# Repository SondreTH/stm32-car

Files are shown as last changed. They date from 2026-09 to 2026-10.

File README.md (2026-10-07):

# Team 7 Autonomous Car (MR2006B)

This is the code for our autonomous car in the MR2006B Industrial Automation course at
Tecnológico de Monterrey. The car has to drive a circuit of about 150 m by itself, stop
for 10 seconds at three waypoints, avoid obstacles and end where it started. Everything
is controlled by an STM32 Nucleo F446RE board.

## How it works

- **Position:** An encoder on the rear motor measures how far the car has driven, and an
  MPU6050 gyro measures which direction it is pointing. From this the car calculates its
  x and y position 100 times per second.
- **Recording and replaying the route:** First we drive the course manually over Bluetooth
  while the car saves its own path and the waypoints. In automatic mode the car follows
  the saved path using pure pursuit, and slows down to stop on each waypoint.
- **Speed control:** A PI controller uses the encoder to keep the car at the speed we ask for.
- **Obstacles:** An HC SR04 ultrasonic sensor makes the car stop if something is in front of it.
  If the obstacle does not move, the car backs up and drives around it.
- **Communication:** Commands and telemetry (CSV) over Bluetooth and over USB.

## Hardware

| Part | Model |
|---|---|
| Microcontroller | STM32 Nucleo F446RE |
| Drive motor | 25GA370 12 V DC motor with gearbox and encoder |
| Motor driver | L298N |
| Steering | MG996R servo |
| Gyro | MPU6050 |
| Distance sensor | HC SR04 |
| Bluetooth | BT04A (ZS040) |
| Power | 3S LiPo battery, XL4015 buck converter for the servo |

## Folders

| Folder | What is inside |
|---|---|
| `cubeide/` | STM32CubeIDE project (`Team7_Car.ioc` and the C code) |
| `tools/` | Python programs for logging, plotting runs and making paths, plus a simulator |
| `cad/` | 3D printed parts (top plate and sensor holder) |
| `wiring/` | Wiring guide for the circuit board |

How to set up the CubeIDE project is explained in `cubeide/README_CubeIDE.md`.

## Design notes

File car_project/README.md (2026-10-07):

# MR2006B car – complete software v1.3

```
car_project/
  cubeide/          STM32CubeIDE project (Team7_Car.ioc + C code), see cubeide/README_CubeIDE.md
    Team7_Car/Core/Src/car_config.c   every tunable number            <- you edit this
    Team7_Car/Core/Inc/path_data.h    the route the car drives in AUTO <- replaced by DUMP
  tools/            laptop tools (Python 3: pip install pyserial matplotlib)
    car_console.py  terminal + automatic telemetry log + path saving
    plot_run.py     plot a run (where the car went vs. the path)
    path_builder.py make a path from measured legs (alternative to TEACH)
    sim.cpp         PC simulation of the autopilot (optional)
  cad/              3D-printable deck plate + HC-SR04 bracket (.scad + .stl)
  wiring/           team7_wiring.html - perfboard wiring guide (open in a browser)
```

The firmware is the CubeIDE project. It matches the soldered perfboard (servo on PB10 / CN10-25).
(An older Arduino IDE version lived in `car_firmware/`; it was removed but is still in the git history.)

**How the car works**
- **Distance** comes from the encoder. **Heading** comes from the MPU-6050 gyro. Together they give the car's **x/y position**.
- In **TEACH** mode you drive the course once over Bluetooth. The car records its own x/y track, and you mark the 3 waypoints and the finish.
- In **AUTO** the car replays that track by steering toward a point 0.6 m ahead on the path (pure pursuit).
  - It slows down and stops exactly at each waypoint, waits 10 s, and ends at the start.
- **Obstacles:**
  - If something is closer than 40 cm, the car stops and waits.
  - If it's still there after 4 s, the car backs up and drives around it (worth 2 points).
- **Why teach-and-repeat:** errors like a slightly wrong gyro scale are the same during teaching and replay, so they cancel out.
  - In the simulation, a 3 % gyro error gave 1–2 cm waypoint error with a taught path.
  - The same error gave 50–220 cm with a path measured from the map.
  - Real runs will be worse than 1–2 cm, because wheel slip and random drift don't cancel.

---

## 1. Build and flash (STM32CubeIDE)

1. Follow `cubeide/README_CubeIDE.md` section 1 to create the project from `Team7_Car.ioc`, then build and **Run** to flash.
2. Talk to the car with any serial terminal on the ST-LINK COM port at **115200** baud, line ending **Newline**, or with `tools/car_console.py` (better: it logs).

## 2. Wiring

| Part | Part pin | Nucleo pin | Header |
|---|---|---|---|
| Encoder | A / B | PA0 / PA1 | A0 / A1 |
| Encoder | VCC / GND | 3V3 / GND | |
| L298N | ENA (remove jumper) / IN1 / IN2 | PA8 / PB4 / PB5 | D7 / D5 / D4 |
| Servo | signal | PB10 | D6 |
| HC-SR04 | TRIG / ECHO (ECHO via 1k–2k divider) | PB6 / PA7 | D10 / D11 |
| Bluetooth | TXD / RXD | PA10 / PA9 | D2 / D8 |
| MPU-6050 | SDA / SCL | PB9 / PB8 | D14 / D15 |
| Battery monitor | battery+ → 10k → pin → 3.3k → GND | PA4 | A2 |

**Power:**
- Battery → switch → fuse feeds three things:
  - the L298N (motor)
  - a 6 V buck converter (servo only)
  - the 5 V module (Nucleo E5V + sensors)
- All grounds are common.
- Keep the car still for 2 s after power-on while the gyro calibrates.

## 3. This week: sensor bring-up (encoder, gyro, distance sensor)

Send `T 10` to get telemetry. With `car_console.py` it's saved to `tools/logs/` automatically. Record the results in the table in section 9.

**Encoder**
1. **Direction.** Lift the rear wheels and turn one forward by hand: `counts` must go up. If not, set `ENCODER_INVERT` in `car_config.h`.
2. **Motor direction.** Send `P 30`: the wheels must turn forward. If not, set `MOTOR_INVERT` in `car_config.h`. `X` stops.
3. **Deadband.** Send `P 5`, `P 10`, `P 15`, … The lowest value that reliably moves the car is the deadband. Set it with `B`.
4. **Counts per metre (most important).**
   - Send `Z`, then `P 40` along a tape. Send `X` after about 5 m.
   - Counts per metre = counts ÷ metres. Do it 3 times and average. Set it with `C` and in `car_config.c`.
5. **Top speed.** Send `P 100` and read `v_mps`. Set `SPEED_FF ≈ (100 − deadband) / top_speed`.
6. **Speed loop.** Send `V 0.3`: `v_mps` should follow `set_mps` without oscillating. If it oscillates, lower KP. If it's slow to reach the setpoint, raise KI.
7. **Distance.** Send `Z` then `D 5`, 5 times. Stops within a few cm of each other means the encoder is good.

**Steering**

8. **Limits.** Step `U 1500` by 25 µs (`U 1525`, `U 1550`, …) to each end stop. Back off 25 µs if the servo strains. Set `SL`, `SR`, `SC`.
9. **Angle scale.** Send `S 20` and measure the front-wheel angle (a phone protractor app works).
   - Set `SERVO_US_PER_DEG` so that `S 20` really gives 20°.
   - The autopilot depends on this.
10. **Wheelbase and sonar position.**
    - Measure from the front axle to the rear axle and put it in `WHEELBASE_M`.
    - Measure from the rear axle to the sonar face and put it in `SONAR_X_M`.

**Gyro**

11. **Found.** `G` must show `IMU OK`.
12. **Direction.** Send `Z` and rotate the car left by hand: `heading_deg` must go up. If not, set `GYRO_INVERT` in `car_config.h`.
13. **Scale (don't skip).**
    - Put the car against a wall edge, send `Z`, and turn it 5 full turns left. Put it back against the edge.
    - Set `GYRO_SCALE = 1800 / heading shown`.
    - Check it with 5 turns right.
14. **Drift.**
    - Wheels lifted: send `Z`, then `P 30`. After 3 minutes, `heading_deg` should be within about 2°.
    - Standing still, the car corrects its own drift, so test with the motor running.

**Distance sensor**

15. Check `sonar_cm` against a tape at 20, 50 and 100 cm. 400 means nothing is seen.
16. Walk around the car outdoors. It must NOT see the ground, a curb or the step. If it does, mount it higher or tilt it up (the printed bracket has a 3° tilt).

**Put it together**

17. **Odometry.** Send `Z`, drive an L-shape with `V`/`S`, stop, and compare `x_m`, `y_m` with a tape.
18. **Indoor autopilot test.** The built-in demo path is 2 m straight → stop → 90° left turn → 1 m → finish. It needs about 2 × 3 m of floor.
    - Put the car down and press the blue button (or send `GO`).
    - It stops after 2 m for 10 s, then turns and finishes.
19. **Obstacle test.** Run the demo again and step in front of the car.
    - It should stop, then continue when you step away.
    - Put a box in front instead: after 4 s it should back up and drive around the box.

## 4. Commands

| Command | Does |
|---|---|
| `X` | Stop. Also aborts AUTO |
| `V 0.3` / `S 15` | Speed (m/s) / steering (° , + = left) |
| `P 40` / `D 5` | Open-loop motor % / drive 5 m and stop |
| `REC` | Start recording a path. The car's position now = START |
| `WP` | Record a waypoint here (car stopped exactly on it) |
| `NOOBS` | Toggle an obstacle-free zone (e.g. passing close to a wall) |
| `END` | Record the finish here and stop recording |
| `GO` | AUTO: 3 s countdown, gyro calibration, then drive the path |
| `PATH` / `DUMP` / `LOAD` | Show path / print it as `path_data.h` / reload the built-in one |
| `AS 0.3` `LA 0.6` `OB 40` `RR 1` `DO 0.6` | Cruise speed, look-ahead, obstacle stop distance, reroute on/off, detour size (+ = pass on the left) |
| `Z` `GC` `GS` `C` `K` `B` `U` `SC/SL/SR` `WB` | Calibration (see section 3) |
| `T 10` `G` `W 1000` `?` | Telemetry rate, settings, watchdog, help |

**Blue button:**
- In AUTO: abort.
- While moving: stop.
- In TEACH, standing still: record a waypoint.
- Otherwise: start AUTO.

## 5. Teaching the course (the "training drive")

1. **Make a start jig.** Mark the START on the ground at the bell: tape where the two rear wheels go, plus a line for the heading.
   The start heading must be identical every time. It's the biggest single error source.
2. **Set up the phone.** In Serial Bluetooth Terminal, create macro buttons:
   `V 0.2`, `X`, `S 25`, `S 12`, `S 0`, `S -12`, `S -25`, `WP`, `END`.
3. **Start recording.** Put the car in the jig and send `REC`. It calibrates the gyro for 1 s: don't touch it.
4. **Drive the course slowly** (`V 0.2`), in the middle of the sidewalk.
   - Stay away from edges: the detour needs about 0.6 m of room on one side.
   - Smooth driving gives a smooth path.
5. **At each waypoint:** stop so the car is exactly on the marker, then send `WP` (or press the blue button).
   - Use the same point of the car every time (e.g. the rear axle over the mark), because that's the point AUTO will stop on.
6. **At the finish** (back at the bell): stop exactly in the start position and send `END`.
   - It prints the **loop closure**: how far the odometry thinks the finish is from the start. This is your drift over one lap.
7. **Save it.** Send `DUMP`. `car_console.py` saves it to `tools/saved_paths/`.
   - Copy that file over `cubeide/Team7_Car/Core/Inc/path_data.h`, then build and flash. The path is now permanent.
   - To test without re-uploading, `!upload <file>` in the console sends a path into the car's RAM.
8. **Replay.** Put the car in the jig and press the button. Check the waypoint errors and plot the run: `python plot_run.py logs/run_….csv --path ../cubeide/Team7_Car/Core/Inc/path_data.h`.

**Improving accuracy:**
- Run 3 times and measure where the car stops at each waypoint.
- If an error is the same every run, it can be corrected. Nudge that waypoint's x/y in `path_data.h`, or re-teach.
- If the car cuts corners, lower `LA` (look-ahead). If it wobbles on straights, raise it.
- **Time check:** 150 m at 0.3 m/s plus 3 × 10.5 s ≈ 9 min, inside the 15 min limit.
  - Don't go below about 0.2 m/s average.
  - `AS` sets the cruise speed.

## 6. Laptop tools

```
pip install pyserial matplotlib
python tools/car_console.py                 # lists ports
python tools/car_console.py COM5            # USB (115200)
python tools/car_console.py COM7 9600       # Bluetooth COM port
python tools/plot_run.py tools/logs/run_XXXX.csv --path cubeide/Team7_Car/Core/Inc/path_data.h
python tools/path_builder.py tools/course_example.txt -o cubeide/Team7_Car/Core/Inc/path_data.h
```

- **Over Bluetooth:** use `T 5` rather than `T 10`, because 9600 baud is slow.
- **The simulator (optional):** runs the real autopilot code (`cubeide/.../path.c`, `autopilot.c`) on a simulated course.
  Build instructions are at the top of `tools/sim.cpp`, then `./sim 0.01 t`.

## 7. 3D-printed parts (`cad/`)

- **`deck_plate`** – an extra top layer, 180 × 110 × 3 mm.
  - It has a 10 mm grid of M3 holes (screws or zip ties anywhere) and two cable slots.
  - It mounts on four M3 brass standoffs.
  - **Before printing:** measure the spacing of the 4 holes you'll use in the existing upper plate. Set `mount_x` / `mount_y` in the `.scad` file and export a new STL in OpenSCAD (free).
- **`sonar_bracket`** – holds the HC-SR04 at 45 mm height, tilted 3° up. Two slots screw it to the front plate.
  - Check the eye spacing (26 mm) with calipers first.
- **Print:** PLA or PETG, 0.2 mm layers, 20 % infill, no supports.

## 8. Race-day checklist

- [ ] Battery charged, and the voltage shows in `G`
- [ ] The correct `path_data.h` flashed (`PATH` shows 3 STOPs + FINISH)
- [ ] Car in the start jig, heading exact
- [ ] Hands off during the 3 s countdown (gyro calibration)
- [ ] Laptop or phone connected, `T 5` running, to show the telemetry to the professor

## 9. Results table

| Value | Measured |
|---|---|
| ENCODER / MOTOR / GYRO invert | |
| Deadband % | |
| Counts per metre (3 runs) | |
| Top speed at P 100 (m/s) | |
| Servo min / centre / max (µs), µs per degree | |
| Wheelbase, sonar offset (m) | |
| GYRO_SCALE | |
| D 5 result (5 runs) | |
| Loop closure after TEACH (cm) | |
| Waypoint errors, AUTO run 1 / 2 / 3 (cm) | |

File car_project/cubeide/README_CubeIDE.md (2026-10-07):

# Team 7 car – STM32CubeIDE version (v1.3)

The car firmware, written in C with ST's HAL. All pins are set
in **`Team7_Car.ioc`**, so CubeIDE shows them in the Pinout view (the screenshots for the professor).

```
Team7_Car/
  Team7_Car.ioc            CubeMX configuration: pins, clocks, timers, UARTs, I2C, ADC
  Core/Src/main.c          generated by CubeMX + 2 lines of ours (App_Init, App_Loop)
  Core/Src/car_app.c       modes (manual / teach / auto), commands, telemetry
  Core/Src/car_hw.c        encoder, motor, servo, HC-SR04, MPU-6050, battery, buttons
  Core/Src/car_comms.c     USB + Bluetooth text I/O (interrupt driven)
  Core/Src/car_drive.c     odometry and PI speed control loop
  Core/Src/path.c          route + pure-pursuit path following
  Core/Src/autopilot.c     automatic mode state machine (waypoints, obstacles)
  Core/Src/car_config.c    every tunable number      <- edit this one
  Core/Inc/path_data.h     the route for AUTO        <- replaced by DUMP
  (stm32f4xx_hal_msp.c, stm32f4xx_it.c, stm32f4xx_hal_conf.h, main.h: generated, CubeMX rewrites them)
```

## 1. Open it in STM32CubeIDE

1. **File → New → STM32 Project from an Existing STM32CubeMX Configuration File (.ioc)**.
2. Select `Team7_Car/Team7_Car.ioc`. Keep the language **C**, then press **Finish**.
   - CubeIDE creates the project and generates `Drivers/`, the startup file and the linker script.
3. Copy our **`Core/Inc`** and **`Core/Src`** files into the new project's `Core/Inc` and `Core/Src`, replacing the files there.
4. Double-click `Team7_Car.ioc` and press **Project → Generate Code** (Alt+K).
   - CubeMX rewrites its own parts and keeps everything between `USER CODE BEGIN`/`END`.
5. Build with the hammer icon (Ctrl+B), then **Run** to flash the board.

**If the `.ioc` won't open or CubeMX reports errors,** make it yourself in about 10 minutes with the table in section 3.
Then do step 3 and 4 the same way. The code only depends on the pin **labels** and handle names.

**Check after generating:** `main.c` must still contain `#include "car_app.h"`, `App_Init();` and `App_Loop();`.
If they're gone, add them back inside these sections:
- `/* USER CODE BEGIN Includes */` → `#include "car_app.h"`
- `/* USER CODE BEGIN 2 */` → `App_Init();`
- `/* USER CODE BEGIN 3 */` → `App_Loop();`

## 2. Talk to the car

- **USB:** any serial terminal on the ST-LINK COM port at **115200**, line ending **LF/Newline**.
- **Bluetooth:** the BT module's COM port at **9600**. `tools/car_console.py` works with both.
- The commands, telemetry columns, TEACH/AUTO workflow and bring-up tests are in the main `README.md`, sections 3–5.

## 3. Configuration (for the report, and to rebuild the .ioc by hand)

**Board:** NUCLEO-F446RE.
**Clock:** HSI 16 MHz → PLL (M 16, N 336, P 4) → **84 MHz** SYSCLK. APB1 42 MHz, APB2 84 MHz. All timer clocks 84 MHz.
**SYS:** Debug = Serial Wire, Timebase = SysTick.

| Pin | Mode in CubeMX | User label | Connected to | Perfboard |
|---|---|---|---|---|
| PA0 | TIM5_CH1 (Encoder Mode) | ENC_A | Encoder A | CN7-28 |
| PA1 | TIM5_CH2 (Encoder Mode) | ENC_B | Encoder B | CN7-30 |
| PA2 / PA3 | USART2 TX / RX | USART_TX / USART_RX | ST-LINK virtual COM | – |
| PA4 | ADC1_IN4 | BATT_SENSE | Battery divider 10k / 3.3k | CN7-32 |
| PA5 | GPIO_Output | LD2 | Green LED | – |
| PA7 | GPIO_EXTI7 | SONAR_ECHO | HC-SR04 ECHO (via divider) | CN10-15 |
| PA8 | TIM1_CH1 (PWM Generation CH1) | MOTOR_ENA | L298N ENA | CN10-23 |
| PA9 / PA10 | USART1 TX / RX | BT_TX / BT_RX | Bluetooth RXD / TXD | CN10-21 / CN10-33 |
| PB0 | GPIO_Input, pull-up | START_BTN | Start button to GND | CN7-34 |
| PB10 | TIM2_CH3 (PWM Generation CH3) | SERVO_PWM | Servo signal | CN10-25 |
| PB4 | GPIO_Output | MOTOR_IN1 | L298N IN1 | CN10-27 |
| PB5 | GPIO_Output | MOTOR_IN2 | L298N IN2 | CN10-29 |
| PB6 | GPIO_Output | SONAR_TRIG | HC-SR04 TRIG | CN10-17 |
| PB8 / PB9 | I2C1 SCL / SDA | IMU_SCL / IMU_SDA | MPU-6050 | CN10-3 / CN10-5 |
| PC13 | GPIO_Input | B1 | Blue user button | – |

**Peripheral settings**

| Peripheral | Settings | Why |
|---|---|---|
| TIM1 | Clock internal, CH1 PWM, Prescaler 0, Period 16799 | Motor PWM 84 MHz / 16800 = **5 kHz** |
| TIM2 | Clock internal, CH3 PWM, Prescaler 83, Period 19999, Pulse 1500 | 1 tick = 1 µs, 20 ms period = **50 Hz servo** on PB10 |
| TIM5 | Combined channels: Encoder Mode TI1 and TI2, Period 4294967295, Input filter 6 (both); GPIO pull-up on PA0/PA1 | 32-bit hardware quadrature counting (x4) |
| USART1 | Asynchronous, 9600 baud, global interrupt ON | Bluetooth |
| USART2 | Asynchronous, 115200 baud, global interrupt ON | USB virtual COM |
| I2C1 | Fast Mode 400 kHz, on PB8/PB9 | MPU-6050 |
| ADC1 | IN4, 12-bit, software start, sampling 480 cycles | Battery voltage |
| NVIC | EXTI line[9:5], USART1, USART2 enabled | Sonar echo timing, serial RX/TX |

**Same wiring as the soldered board.**
- The servo stays on **PB10 (CN10-25)** with real hardware PWM from TIM2 channel 3.
- The encoder stays on PA0/PA1 but is counted by **TIM5**, because TIM2 is busy with the servo.
- Microsecond timing (sonar) comes from SysTick, so no extra timer is needed.

## 4. Screenshots for the professor

In CubeIDE with `Team7_Car.ioc` open:

1. **Pinout view:** the whole chip with all labels. Right-click → *Pinout* to zoom in if needed.
2. **System view → TIM5:** encoder mode settings.
3. **TIM1 and TIM2:** PWM parameters (prescaler, period).
4. **USART1, USART2, I2C1, ADC1:** parameter settings.
5. **NVIC:** enabled interrupts.
6. **Clock Configuration tab:** 84 MHz clock tree.

## 5. Debugging with Live Expressions

Run → **Debug**, then add these in the *Live Expressions* view:

- **Encoder and speed:** `drv.distance`, `drv.speed`, `drv.setpoint`, `motorPct`, `TIM5->CNT`
- **Gyro:** `headingDeg`, `gyroRateDps`, `gyroBiasDps`, `imuOk`
- **Position and sensors:** `drv.x`, `drv.y`, `sonarCm`, `steerDeg`, `battV`
- **Autonomous mode:** `carMode`, `ap.state`, `fol.sNow`, `fol.cte`

If a value shows *optimized out*, set the build to **Debug** (`-Og`).

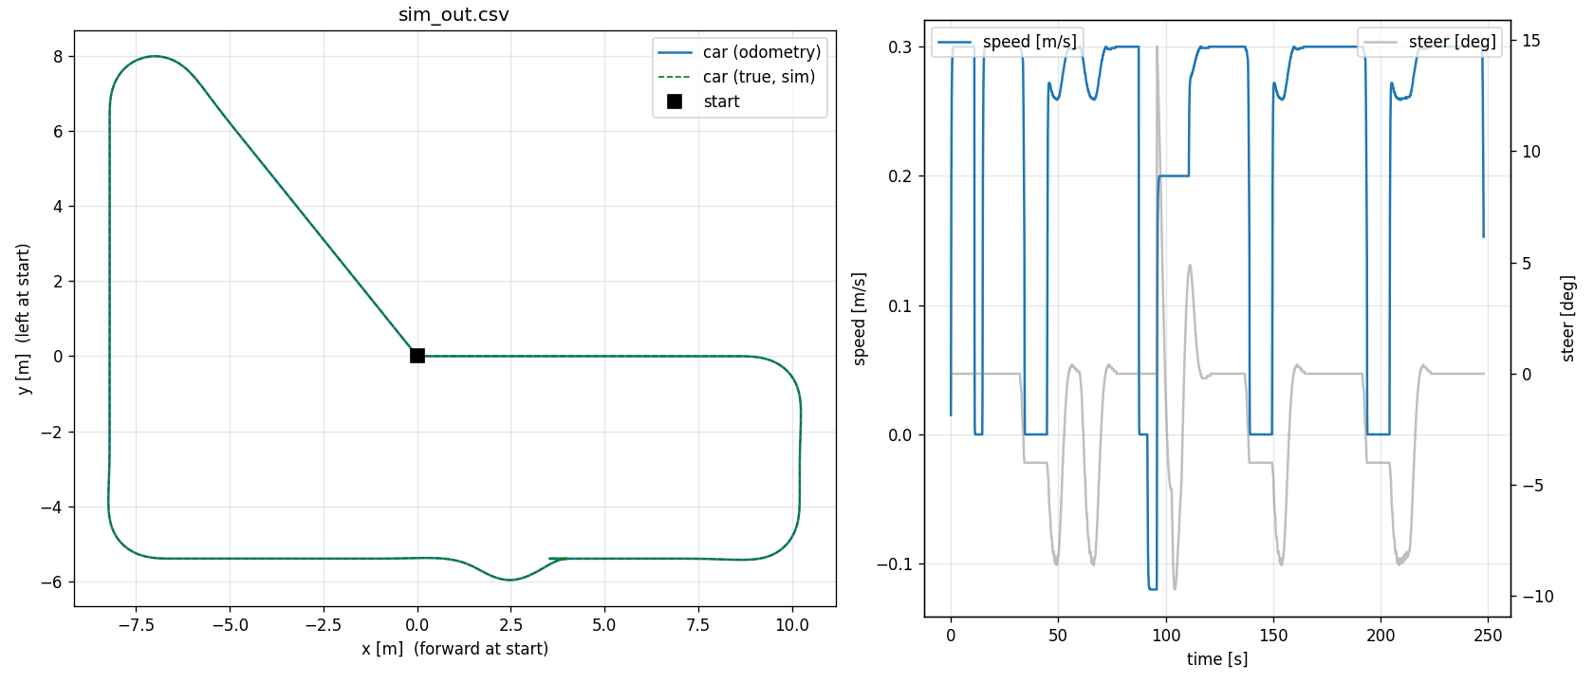
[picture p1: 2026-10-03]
car_project/tools/sim_example.png

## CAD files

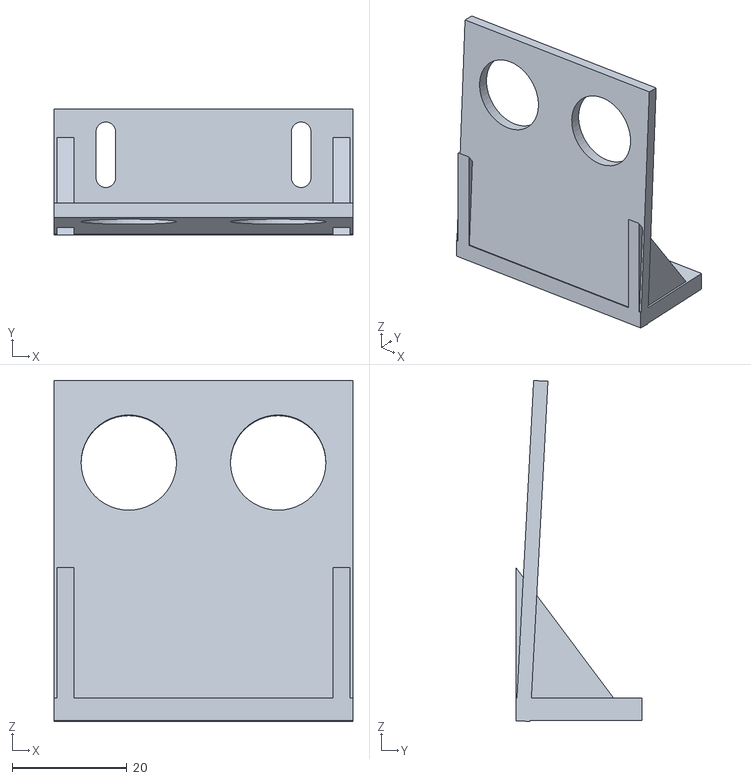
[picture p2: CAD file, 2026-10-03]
car_project/cad/sonar_bracket.stl
52.0 x 22.0 x 59.3

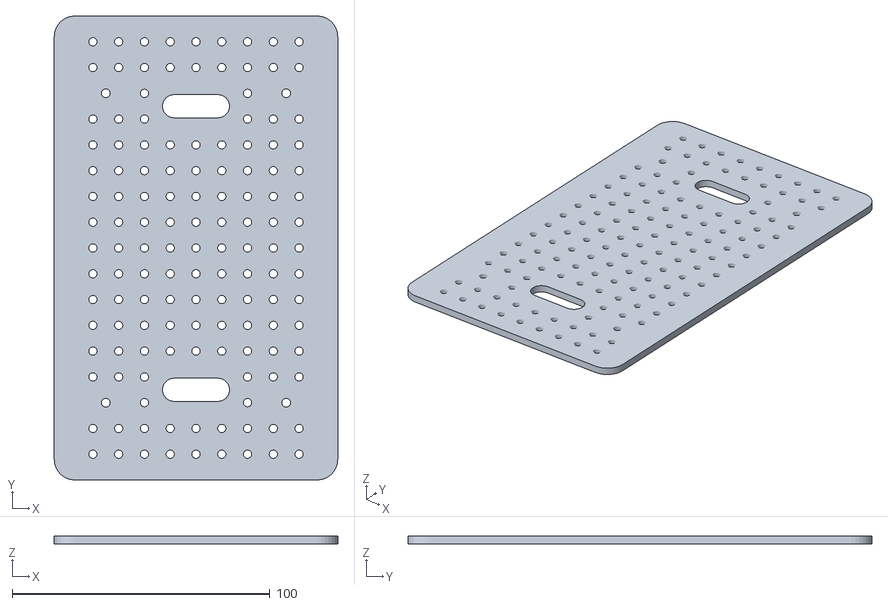
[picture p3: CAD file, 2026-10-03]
car_project/cad/deck_plate.stl
110.0 x 180.0 x 3.00

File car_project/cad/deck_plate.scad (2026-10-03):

// =====================================================================
//  deck_plate.scad  -  extra top deck for the MR2006B car
//
//  A flat plate with a 10 mm grid of M3 holes (screws, standoffs or zip
//  ties anywhere), 4 mounting holes for brass standoffs, and two cable
//  slots. Mount it on M3 brass standoffs screwed into the existing upper
//  plate.
//
//  HOW TO FIT IT TO YOUR CAR (2 minutes with a ruler):
//   1. Pick 4 holes in the existing upper plate for the new standoffs.
//   2. Measure their centre-to-centre spacing across (x) and along (y).
//   3. Put the numbers in mount_x / mount_y below (or edit mount_holes).
//   4. OpenSCAD (free): F6 to render, File > Export > STL. Print flat.
//  Print: PLA/PETG, 0.2 mm layers, 3 walls, 20 % infill, no supports.
// =====================================================================

/* [Plate] */
plate_w      = 110;   // across the car (x), mm
plate_l      = 180;   // along the car (y), mm
thickness    = 3;     // mm (3 is stiff enough; 4 for a heavy battery)
corner_r     = 8;

/* [Mounting to the chassis] */
mount_x      = 70;    // centre-to-centre spacing across, mm   <- MEASURE
mount_y      = 120;   // centre-to-centre spacing along, mm    <- MEASURE
mount_offset_y = 0;   // shift the hole pattern forward (+) / back (-)
mount_d      = 3.4;   // M3 clearance
mount_boss_d = 9;     // solid ring around each mounting hole

/* [Grid] */
grid_pitch   = 10;
grid_d       = 3.2;   // fits M3 screws and 2.5 mm zip ties
edge_margin  = 6;

/* [Cable slots] */
slot_w       = 26;
slot_h       = 9;
slot_y       = [55, -55];   // positions along the car (0 = centre)

$fn = 32;

mount_holes = [for (sx = [-1, 1], sy = [-1, 1]) [sx * mount_x / 2, sy * mount_y / 2 + mount_offset_y]];

module rounded_rect(w, l, r, h) {
  linear_extrude(h)
    offset(r) offset(-r) square([w, l], center = true);
}

function near_mount(p) = min([for (m = mount_holes) norm(p - m)]) < mount_boss_d / 2 + grid_d / 2 + 1;
function in_slot(p) = len([for (sy = slot_y) if (abs(p[0]) < slot_w / 2 + grid_d && abs(p[1] - sy) < slot_h / 2 + grid_d) 1]) > 0;

difference() {
  rounded_rect(plate_w, plate_l, corner_r, thickness);

  // mounting holes
  for (m = mount_holes) translate([m[0], m[1], -1]) cylinder(d = mount_d, h = thickness + 2);

  // grid
  nx = floor((plate_w - 2 * edge_margin) / grid_pitch / 2);
  ny = floor((plate_l - 2 * edge_margin) / grid_pitch / 2);
  for (ix = [-nx : nx], iy = [-ny : ny]) {
    p = [ix * grid_pitch, iy * grid_pitch];
    if (!near_mount(p) && !in_slot(p))
      translate([p[0], p[1], -1]) cylinder(d = grid_d, h = thickness + 2);
  }

  // cable slots
  for (sy = slot_y)
    translate([0, sy, -1]) linear_extrude(thickness + 2)
      offset(slot_h / 2 - 0.01) square([slot_w - slot_h, 0.02], center = true);
}

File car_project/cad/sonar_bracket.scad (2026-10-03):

// =====================================================================
//  sonar_bracket.scad  -  front bracket for the HC-SR04
//
//  The two "eyes" push through the round holes from behind; a drop of
//  hot glue (or two small zip ties) holds the board. The foot has two
//  M3 slots to screw it onto the front bumper plate or the deck.
//
//  Check with calipers before printing: eye diameter (usually 16 mm)
//  and centre-to-centre spacing of the eyes (usually ~26 mm).
//  Print standing on the foot, no supports.
// =====================================================================

eye_d        = 16.6;  // hole for the transducers (16 mm + clearance)
eye_spacing  = 26;    // centre-to-centre                       <- CHECK
face_w       = 52;
face_t       = 2.5;
sensor_h     = 45;    // eye centre height above the foot, mm
                      // (higher = fewer false alarms from the ground)
tilt_up      = 3;     // degrees, aims slightly up to ignore the ground
foot_d       = 22;    // foot depth
foot_t       = 4;
slot_len     = 8;     // M3 slots, lets you adjust the position
slot_spacing = 34;

$fn = 48;
face_h = sensor_h + eye_d / 2 + 6;

difference() {
  union() {
    // foot
    translate([-face_w / 2, 0, 0]) cube([face_w, foot_d, foot_t]);
    // face (tilted back by tilt_up)
    rotate([-tilt_up, 0, 0]) translate([-face_w / 2, 0, 0]) cube([face_w, face_t, face_h]);
    // gussets
    for (sx = [-1, 1])
      translate([sx * (face_w / 2 - 2) - 1.5, 0, 0])
        rotate([90, 0, 90]) linear_extrude(3)
          polygon([[0, 0], [foot_d - 2, 0], [0, face_h * 0.45]]);
  }
  // eyes
  for (sx = [-1, 1])
    rotate([-tilt_up, 0, 0]) translate([sx * eye_spacing / 2, -1, sensor_h])
      rotate([-90, 0, 0]) cylinder(d = eye_d, h = face_t + 2);
  // M3 slots in the foot
  for (sx = [-1, 1])
    translate([sx * slot_spacing / 2, foot_d / 2 + 3, -1]) hull() {
      translate([0, -slot_len / 2, 0]) cylinder(d = 3.4, h = foot_t + 2);
      translate([0,  slot_len / 2, 0]) cylinder(d = 3.4, h = foot_t + 2);
    }
}

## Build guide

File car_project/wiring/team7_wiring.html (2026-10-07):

MR2006B · Team 7 · firmware v1.3

# Team 7 Car Wiring

What to solder where on the perfboard that sits on the NUCLEO-F446RE's inner morpho rows. It matches the pins in Team7_Car.ioc (CubeIDE).

VBAT 11–12.6 V 6 V servo 5 V 3.3 V GND Signal Motor current

## Connector rule

Male pins on the perfboard

Every header J1–J6 on the perfboard is a male pin header. Cables end in female plugs. Your motor/encoder and servo cables already work this way.

Modules: female–female jumpers

The Bluetooth, MPU-6050, HC-SR04 and L298N logic pins are male pins on the module, so connect them with female–female Dupont wires (a 4-wire ribbon keeps them together).

Power: screw terminals

The 5 V and 6 V inputs (J7, J8) and the battery wiring use screw terminals or soldered wire. Dupont plugs can wiggle loose and don't like amps.

Label every plug

J4, J5 and J6 are all 4-pin. Mark each header and its cable with the same colour dot. Swapping them puts 5 V on a signal pin.

## Power

The battery feeds a terminal block (for example WAGO 221). From there each part gets its own supply wire. Only 5 V, 6 V and the battery-sense wire go to the perfboard.

Solder a 1000 µF 16 V capacitor across J2 pins 1–2 (servo), and 100 µF across the 5 V rail. Set both bucks with a multimeter before anything is plugged into them.

## Nucleo pins under the perfboard

Top view, USB end at the top. Your female headers sit on the inner row of each side. Coloured dots are the pins to wire. Row 1 and row 19 are unused, so either end can be cut off.

Leave CN7-18 (+5V) unconnected. With the power jumper on E5V it is the same 5 V anyway, and wiring both invites two supplies fighting when someone moves the jumper.

## Perfboard headers

Pin 1 of each header is listed first. The pin order matches the device or cable, so a straight 4-wire ribbon or the existing plug fits without crossing wires. Check the motor cable colours against your motor's label before soldering J1.

## Before the first power-up

1. Continuity: the GND rail beeps to CN7-20, CN7-22 and CN10-9.
2. No shorts: 5V–GND, 3V3–GND, 6V–GND and VBAT–GND must not beep.
3. Power the bucks with nothing attached. Set 6.0 V (XL4015) and 5.0 V.
4. Power jumper JP5 on E5V. Switch the battery on first, then plug in USB.
5. Measure PA7 (CN10-15) while holding a hand 10 cm in front of the HC-SR04: it must never go above 3.3 V.
6. Only then plug the servo, motor and modules into their headers.

The L298N's 5V screw pin is an output from its own regulator. Connecting it to your 5 V rail makes two supplies fight. Leave it empty.

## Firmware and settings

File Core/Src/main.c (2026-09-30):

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
/* Includes ------------------------------------------------------------------*/
#include "main.h"

/* USER CODE BEGIN PD */
#define IN1_PORT        GPIOA
#define IN1_PIN         GPIO_PIN_8
#define IN2_PORT        GPIOB
#define IN2_PIN         GPIO_PIN_10
/* USER CODE END PD */

TIM_HandleTypeDef htim2;

UART_HandleTypeDef huart1;
UART_HandleTypeDef huart2;

/* USER CODE BEGIN PV */
extern UART_HandleTypeDef huart1;
uint8_t rx_data = 0;
/* USER CODE END PV */

void SystemClock_Config(void);
static void MX_GPIO_Init(void);
static void MX_USART2_UART_Init(void);
static void MX_USART1_UART_Init(void);
static void MX_TIM2_Init(void);
/* USER CODE BEGIN 0 */
volatile int position = 0;
float distance_meters = 0.0;

const float movement = 1.0/1618.0;
/* USER CODE END 0 */

/**
  * @brief  The application entry point.
  * @retval int
  */


int main(void)
{

  /* MCU Configuration--------------------------------------------------------*/

  /* Reset of all peripherals, Initializes the Flash interface and the Systick. */
  HAL_Init();

  /* Configure the system clock */
  SystemClock_Config();

  /* Initialize all configured peripherals */
  MX_GPIO_Init();
  MX_USART2_UART_Init();
  MX_USART1_UART_Init();
  MX_TIM2_Init();
  /* USER CODE BEGIN 2 */
  /* Ensure motors are stopped on startup */
  HAL_GPIO_WritePin(IN1_PORT, IN1_PIN, GPIO_PIN_RESET);
  HAL_GPIO_WritePin(IN2_PORT, IN2_PIN, GPIO_PIN_RESET);

  /* Defining the normal speed which the car drives with*/
  HAL_TIM_PWM_Start(&htim2, TIM_CHANNEL_1);
  __HAL_TIM_SET_COMPARE(&htim2, TIM_CHANNEL_1, 50);
  /* USER CODE END 2 */

  /* Infinite loop */
  /* USER CODE BEGIN WHILE */


  while (1)
  {
	  distance_meters = position*movement;

      /* Bluetooth commands from the phone */
      if (HAL_UART_Receive(&huart1, &rx_data, 1, 10) == HAL_OK)
      {
          switch (rx_data)
          {
              case 'f': /* Drive Forward */
                  HAL_GPIO_WritePin(IN1_PORT, IN1_PIN, GPIO_PIN_SET);
                  HAL_GPIO_WritePin(IN2_PORT, IN2_PIN, GPIO_PIN_RESET);
                  break;

              case 'b': /* Drive Backward */
                  HAL_GPIO_WritePin(IN1_PORT, IN1_PIN, GPIO_PIN_RESET);
                  HAL_GPIO_WritePin(IN2_PORT, IN2_PIN, GPIO_PIN_SET);
                  break;

              case 's': /* Stop */
              default:
                  HAL_GPIO_WritePin(IN1_PORT, IN1_PIN, GPIO_PIN_RESET);
                  HAL_GPIO_WritePin(IN2_PORT, IN2_PIN, GPIO_PIN_RESET);
                  break;

              case '1': /*  (20%) */
                  __HAL_TIM_SET_COMPARE(&htim2, TIM_CHANNEL_1, 20);
                  break;

              case '2': /* (40%) */
                  __HAL_TIM_SET_COMPARE(&htim2, TIM_CHANNEL_1, 40);
                  break;

              case '3': /* (60%) */
                  __HAL_TIM_SET_COMPARE(&htim2, TIM_CHANNEL_1, 60);
                  break;

              case '4': /* (80%) */
                  __HAL_TIM_SET_COMPARE(&htim2, TIM_CHANNEL_1, 80);
                  break;

              case '5': /*  (100%) */
                  __HAL_TIM_SET_COMPARE(&htim2, TIM_CHANNEL_1, 100);
                  break;
          }
      }

      /* Securing the board never freezes */
      __HAL_UART_CLEAR_OREFLAG(&huart1);

    /* USER CODE END WHILE */

    /* USER CODE BEGIN 3 */
  }
  /* USER CODE END 3 */
}

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
/* USER CODE BEGIN 4 */
void HAL_GPIO_EXTI_Callback(uint16_t GPIO_Pin)
{
  /* Checking if ENC_A gave the signal */
  if (GPIO_Pin == ENC_A_Pin)
  {
    /* Checking direction with ENC_B */
    if (HAL_GPIO_ReadPin(ENC_B_GPIO_Port, ENC_B_Pin) == GPIO_PIN_SET)
    {
      position++;
    }
    else
    {
      position--;
    }
  }
}
/* USER CODE END 4 */
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


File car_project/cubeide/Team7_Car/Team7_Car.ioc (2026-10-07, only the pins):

Mcu.UserName=STM32F446RETx
PA0-WKUP.GPIO_Label=ENC_A
PA0-WKUP.Signal=S_TIM5_CH1
PA1.GPIO_Label=ENC_B
PA1.Signal=S_TIM5_CH2
PA10.GPIO_Label=BT_RX
PA10.Signal=USART1_RX
PA13.GPIO_Label=TMS
PA13.Signal=SYS_JTMS-SWDIO
PA14.GPIO_Label=TCK
PA14.Signal=SYS_JTCK-SWCLK
PA2.GPIO_Label=USART_TX
PA2.Signal=USART2_TX
PA3.GPIO_Label=USART_RX
PA3.Signal=USART2_RX
PA4.GPIO_Label=BATT_SENSE
PA4.Signal=ADCx_IN4
PA5.GPIO_Label=LD2 [Green Led]
PA5.Signal=GPIO_Output
PA7.GPIO_Label=SONAR_ECHO
PA7.Signal=GPXTI7
PA8.GPIO_Label=MOTOR_ENA
PA8.Signal=S_TIM1_CH1
PA9.GPIO_Label=BT_TX
PA9.Signal=USART1_TX
PB0.GPIO_Label=START_BTN
PB0.Signal=GPIO_Input
PB10.GPIO_Label=SERVO_PWM
PB10.Signal=S_TIM2_CH3
PB3.GPIO_Label=SWO
PB3.Signal=SYS_JTDO-SWO
PB4.GPIO_Label=MOTOR_IN1
PB4.Signal=GPIO_Output
PB5.GPIO_Label=MOTOR_IN2
PB5.Signal=GPIO_Output
PB6.GPIO_Label=SONAR_TRIG
PB6.Signal=GPIO_Output
PB8.GPIO_Label=IMU_SCL
PB8.Signal=I2C1_SCL
PB9.GPIO_Label=IMU_SDA
PB9.Signal=I2C1_SDA
PC13.GPIO_Label=B1 [Blue PushButton]
PC13.Signal=GPIO_Input
PC14-OSC32_IN.Signal=RCC_OSC32_IN
PC15-OSC32_OUT.Signal=RCC_OSC32_OUT
PH0-OSC_IN.Signal=RCC_OSC_IN
PH1-OSC_OUT.Signal=RCC_OSC_OUT

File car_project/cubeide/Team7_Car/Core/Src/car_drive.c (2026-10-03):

/* car_drive.c - odometry and PI speed control (see car_drive.h) */
#include "car_drive.h"
#include "car_hw.h"
#include "car_config.h"
#include <math.h>

#ifndef M_PI
#define M_PI 3.14159265358979f
#endif

DriveState drv = { DM_STOP, 0, 0, 0, 0, 0, 0, 0, 0, 0, 0, 0, 0, 0.2f, 0, false };

static float clampf_(float v, float lo, float hi) { return v < lo ? lo : (v > hi ? hi : v); }

void drive_stop(void) {
  drv.mode = DM_STOP;
  drv.target = drv.setpoint = 0;
  drv.integ = 0;
  motor_brake();
}
void drive_open(float pct)  { drv.mode = DM_OPEN; drv.openPct = pct; drv.integ = 0; }
void drive_speed(float mps) { drv.mode = DM_SPEED; drv.target = mps; }

void drive_distance(float meters, float cruise) {
  drv.moveStart  = drv.distance;
  drv.moveGoal   = drv.distance + meters;
  drv.moveCruise = fabsf(cruise);
  drv.moveDone   = false;
  drv.mode       = DM_DISTANCE;
}

void drive_zero(void) {
  encoder_zero();
  drv.lastCount = 0;
  drv.distance = 0;
  drv.x = drv.y = 0;
}

/* certainly not moving: braked and no encoder counts for 0.3 s */
bool drive_is_still(void) { return drv.mode == DM_STOP && drv.stillTicks > CONTROL_HZ * 3 / 10; }

/* encoder gives the distance step, gyro the direction (midpoint rule) */
void odometry_update(float headingBeforeDeg, float headingAfterDeg) {
  float ds = drv.lastDelta / COUNTS_PER_METER;
  float th = 0.5f * (headingBeforeDeg + headingAfterDeg) * (float)M_PI / 180.0f;
  drv.x += ds * cosf(th);
  drv.y += ds * sinf(th);
}

/* PI with feed-forward, deadband compensation and anti-windup -> motor % */
static float speed_pi(float sp, float meas, float dt) {
  if (fabsf(sp) < 0.005f) { drv.integ = 0; return 0; }
  float err = sp - meas;
  float u = SPEED_FF * sp + (sp > 0 ? MOTOR_DEADBAND_PCT : -MOTOR_DEADBAND_PCT) + SPEED_KP * err + drv.integ;
  if (fabsf(u) < 100.0f || ((u > 0) != (err > 0))) {
    drv.integ += SPEED_KI * err * dt;
    drv.integ = clampf_(drv.integ, -60.0f, 60.0f);
  }
  return clampf_(u, -100.0f, 100.0f);
}

void drive_update(float dt) {
  /* odometry */
  int32_t c = encoder_count();
  int32_t dc = c - drv.lastCount;
  drv.lastCount = c;
  drv.lastDelta = dc;
  if (dc == 0) { if (drv.stillTicks < 60000) drv.stillTicks++; } else drv.stillTicks = 0;
  float vRaw = (dc / COUNTS_PER_METER) / dt;
  drv.speed += SPEED_LPF * (vRaw - drv.speed);
  drv.distance = c / COUNTS_PER_METER;

  /* distance move: plan the speed from the remaining distance */
  if (drv.mode == DM_DISTANCE) {
    float remaining = drv.moveGoal - drv.distance;
    float dir = (drv.moveGoal >= drv.moveStart) ? 1.0f : -1.0f;
    if (remaining * dir <= MOVE_STOP_TOL) { drive_stop(); drv.moveDone = true; return; }
    float v = sqrtf(2.0f * MOVE_DECEL * fabsf(remaining));
    v = clampf_(v, MOVE_CREEP, drv.moveCruise);
    drv.target = dir * v;
  }

  switch (drv.mode) {
    case DM_STOP: motor_brake(); break;
    case DM_OPEN: motor_set(drv.openPct); break;
    case DM_SPEED:
    case DM_DISTANCE: {
      float step = MAX_ACCEL * dt;
      drv.setpoint += clampf_(drv.target - drv.setpoint, -step, step);
      if (drv.mode == DM_DISTANCE && fabsf(drv.target) < fabsf(drv.setpoint)) drv.setpoint = drv.target;
      if (drv.mode == DM_SPEED && fabsf(drv.target) < 0.005f && fabsf(drv.setpoint) < 0.005f) {
        motor_brake(); drv.integ = 0;
      } else {
        motor_set(speed_pi(drv.setpoint, drv.speed, dt));
      }
      break;
    }
  }
}

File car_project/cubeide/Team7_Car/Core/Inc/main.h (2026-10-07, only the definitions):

#define B1_Pin GPIO_PIN_13
#define B1_GPIO_Port GPIOC
#define ENC_A_Pin GPIO_PIN_0
#define ENC_A_GPIO_Port GPIOA
#define ENC_B_Pin GPIO_PIN_1
#define ENC_B_GPIO_Port GPIOA
#define USART_TX_Pin GPIO_PIN_2
#define USART_TX_GPIO_Port GPIOA
#define USART_RX_Pin GPIO_PIN_3
#define USART_RX_GPIO_Port GPIOA
#define BATT_SENSE_Pin GPIO_PIN_4
#define BATT_SENSE_GPIO_Port GPIOA
#define LD2_Pin GPIO_PIN_5
#define LD2_GPIO_Port GPIOA
#define SONAR_ECHO_Pin GPIO_PIN_7
#define SONAR_ECHO_GPIO_Port GPIOA
#define SONAR_ECHO_EXTI_IRQn EXTI9_5_IRQn
#define START_BTN_Pin GPIO_PIN_0
#define START_BTN_GPIO_Port GPIOB
#define SERVO_PWM_Pin GPIO_PIN_10
#define SERVO_PWM_GPIO_Port GPIOB
#define MOTOR_ENA_Pin GPIO_PIN_8
#define MOTOR_ENA_GPIO_Port GPIOA
#define BT_TX_Pin GPIO_PIN_9
#define BT_TX_GPIO_Port GPIOA
#define BT_RX_Pin GPIO_PIN_10
#define BT_RX_GPIO_Port GPIOA
#define TMS_Pin GPIO_PIN_13
#define TMS_GPIO_Port GPIOA
#define TCK_Pin GPIO_PIN_14
#define TCK_GPIO_Port GPIOA
#define SWO_Pin GPIO_PIN_3
#define SWO_GPIO_Port GPIOB
#define MOTOR_IN1_Pin GPIO_PIN_4
#define MOTOR_IN1_GPIO_Port GPIOB
#define MOTOR_IN2_Pin GPIO_PIN_5
#define MOTOR_IN2_GPIO_Port GPIOB
#define SONAR_TRIG_Pin GPIO_PIN_6
#define SONAR_TRIG_GPIO_Port GPIOB
#define IMU_SCL_Pin GPIO_PIN_8
#define IMU_SCL_GPIO_Port GPIOB
#define IMU_SDA_Pin GPIO_PIN_9
#define IMU_SDA_GPIO_Port GPIOB

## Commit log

2026-10-03 Restructure into car_project/ with new CubeIDE project, tools, CAD and wiring
    Moves the Arduino firmware into car_project/car_firmware, replaces
    legacy_cubeide with the Team7_Car CubeIDE project, drops committed
    build output, and adds tools, CAD files and the wiring diagram.
    [deck_plate.scad, deck_plate.stl, sonar_bracket.scad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]
2026-10-07 Swap L298N IN1/IN2 pins: IN1 is now PB4, IN2 is now PB5
    Matches the rewired car. Updated the .ioc labels, generated main.h/main.c,
    Arduino config.h, and the pin tables in car_config.h, README_CubeIDE.md
    and the wiring page.
    [Team7_Car.ioc, car_config.h, main.c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]
2026-10-07 Remove legacy Arduino firmware; CubeIDE project is the only firmware
    Deleted car_project/car_firmware/ (still available in git history).
    Pointed the README, tools and wiring page at the CubeIDE project instead,
    and made path_builder.py emit the CubeIDE path_data.h format
    (#include "path.h", static arrays) so its output drops straight in.
    Also fixed the README wiring table, which still had the old IN1/IN2 pins.
    [car_console.py, path_builder.py, plot_run.py]
2026-10-07 Root README: drop removed Arduino folder from the folder table
2026-10-08 here we go
    [deck_plate.scad, deck_plate.stl, sonar_bracket.scad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]
2026-10-09 Rename the project to stm32-car everywhere
    The project had four names: Car7_A01832890 (.project), Hakons_leg
    (.ioc), A2.1_A01832889 (.cproject) and whatever folder it was cloned
    into. Eclipse refuses to import a project inside the workspace folder
    when the folder name differs from the project name, and the .cproject
    build path pointed at the A2.1_A01832889 project's folder. Everything
    is now stm32-car, matching the repo name so a default clone just works.
2026-10-09 Add Activity 2.5 base: motor + encoder project
    Stripped copy of the Team7_Car firmware for Activity 2.5 (time
    interrupts and motor speed): TIM1 motor PWM, TIM5 encoder, USB and
    Bluetooth commands, blue button and LD2.
    The activity was handed out as just an .ioc plus Core sources, to be
    turned into a project by hand. It is now a complete stm32-car project
    like the stm32-car branch: the .ioc was migrated to CubeMX 6.13 /
    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
2026-10-14 Added support for OLED display showing uptime n motor usage
2026-10-19 Implementation of a PID controller
2026-10-21 Activity 2.6: TIM3 control interrupt, position PID, timed run, obstacle stop
    - TIM3 update interrupt (PSC 839, ARR 9999 -> 10 Hz) runs the 100 ms
    control step in HAL_TIM_PeriodElapsedCallback() instead of polling.
    - The PID now closes the position loop: Pos_Ref (area under the speed
    profile) vs the encoder distance, with SP_Vel as feed-forward.
    - Timed run: with tt > 0, d covers the distance in tt seconds with
    ramps ta/td (Sn = D / (T - (ta + td)/2)).
    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
2026-11-11 OLED and MPU-6050 share I2C1; mark run variables set in the TIM3 interrupt volatile
2026-11-11 Position loop: kick-start, anti-windup, settle phase, reverse runs; battery calibration
    The car needs about 60 % motor power to start moving but the motor map
    starts at 45 %, so short runs stood still until the integral had grown,
    then overshot, and very short runs never moved.
    car_drive.c
    - Kick-start: a standing car gets at least MOTOR_START_PCT until the
    encoder sees it move, growing by 20 %/s while it still stands.
    - Anti-windup: the integral only grows while the motor can follow (not
    standing, not at 100 %, not paused); the I term is limited to 10 cm/s.
    - During the profile the motor never drives against the run: a car ahead
    of the reference coasts or brakes.
    - New state 4 (settl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
2026-11-11 README for main, .claude documentation, setup guide, tools for the current firmware
    - README.md: what the car does now, pins, commands, how a run works, how
    to tune it, the battery reading, where the old autopilot code is.
    - docs/setup.md: the team setup and Git workflow from the stm32-car branch.
    - .claude/: project documentation (architecture, control loop, hardware,
    commands, history of the branches, open problems).
    - tools/plot_run.py plots distance-run telemetry (reference, measured,
    error, speed, motor %).
    - tools/build_check.sh compiles the firmware from a terminal.
